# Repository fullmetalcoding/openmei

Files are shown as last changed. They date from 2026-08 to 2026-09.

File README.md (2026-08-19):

<p align="center">
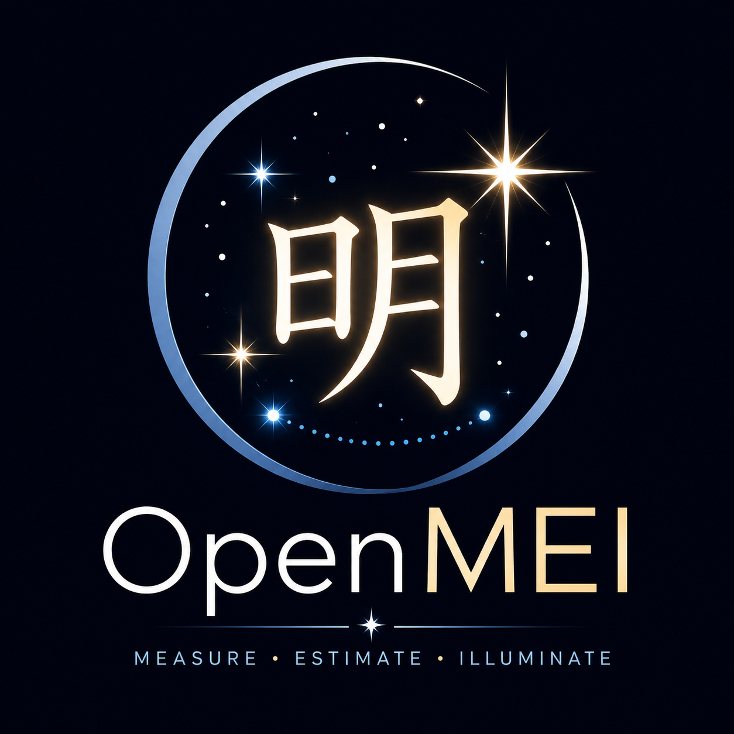
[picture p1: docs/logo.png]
OpenMEI logo
  
</p>

# OpenMEI

**OpenMEI** is an open-source **Differential Image Motion Monitor (DIMM)** application for measuring astronomical seeing.

It acquires short-exposure images of a star through a two-aperture DIMM mask, measures the differential motion of the resulting stellar images, and converts the longitudinal and transverse image-motion variances into estimates of the Fried parameter $r_0$ and atmospheric seeing.

OpenMEI is intended both as a practical seeing monitor and as an instrument whose measurement chain can be inspected, calibrated, reproduced, and validated.

Current features include:

* Real-time camera acquisition and centroid tracking
* Longitudinal and transverse differential image-motion measurement
* Fried parameter $r_0$ estimation
* Seeing FWHM estimation
* Zenith correction
* Projection of seeing onto a separate science target altitude
* Finite-exposure correction using interleaved exposures
* Centroid-noise bias estimation and subtraction
* Synthetic camera backend with known atmospheric ground truth
* ZWO ASI camera support
* SVBONY camera support
* ToupTek/ToupCam camera support
* ASCOM Alpaca `ObservingConditions` interface
* Persistent configuration and measurement metadata
* Raw centroid logging for later re-analysis (WIP)

OpenMEI is written in C++17 and uses SDL3, Dear ImGui, ImPlot, OpenGL, cpp-httplib, and nlohmann/json.

---

## What is a DIMM?

A **Differential Image Motion Monitor** measures astronomical seeing by measuring how atmospheric turbulence causes the apparent position of a star to move.

A conventional DIMM places a mask over the entrance pupil of a telescope. The mask contains two circular sub-apertures separated by a known baseline.

One aperture contains a small wedge prism or equivalent optical element that slightly deflects its beam.

Instead of one stellar image, the camera therefore sees two:

```text
                 incoming starlight
                        ↓
               ┌─────────────────┐
               │   ○         ○   │
               │             /   │
               │ aperture   /    │
               │          wedge  │
               └─────────────────┘
                       DIMM mask
                          ↓
                       telescope
                          ↓
                       camera

                     ★       ★
                    spot A   spot B
```

Both images are produced by the **same star**, but they have passed through two different regions of the telescope pupil.

Atmospheric turbulence causes the local wavefront slope over each sub-aperture to fluctuate. The two stellar images therefore move relative to one another.

The fundamental DIMM measurement is not the absolute position of either star image. It is their separation:

```math
\Delta x = x_2-x_1
\\
\Delta y = y_2-y_1
```
Because telescope tracking errors, mount vibration, and much of the mechanical motion move both images together, subtracting the two centroid positions strongly rejects common-mode motion.

This is the key advantage of the DIMM technique.

---

## Longitudinal and transverse motion

The differential displacement is resolved into two components relative to the baseline between the two sub-apertures:

* **Longitudinal** — parallel to the aperture baseline
* **Transverse** — perpendicular to the aperture baseline

For each acquired burst, OpenMEI determines the variance of both components:

```math
\sigma_l^2
```

and

```math
\sigma_t^2
```

Under Kolmogorov turbulence, these variances are related to the atmospheric coherence length, or **Fried parameter**, $r_0$.

OpenMEI represents the relationship as

```math
\sigma^2 =
K \lambda^2 D^{-1/3} r_0^{-5/3}
```

where:

* $D$ is the sub-aperture diameter
* $d$ is the center-to-center aperture separation
* $\lambda$ is the reporting wavelength
* $K$ is the longitudinal or transverse DIMM response coefficient
* $r_0$ is the Fried parameter

The geometry is commonly represented by

```math
b = \frac{d}{D}
```

For the classic Sarazin & Roddier approximation, OpenMEI uses

```math
K_l =
2c
\left[
1-\frac{0.0968}{c}b^{-1/3}
\right]
```

and

```math
K_t =
2c
\left[
1-\frac{0.1450}{c}b^{-1/3}
\right]
```

where $c=0.179$ for the original Sarazin & Roddier formulation.

OpenMEI also provides the corrected $c=0.182$ coefficient discussed in the mini-DIMM analysis by Yu et al.

The classic approximation should normally be used with

```math
\frac{d}{D} \ge 2
```

For smaller aperture separations, more exact DIMM response coefficients should be used instead.

---

## From differential motion to seeing

Once $r_0$ has been estimated, OpenMEI converts it to the conventional long-exposure seeing FWHM using

```math
\epsilon = 0.98\frac{\lambda}{r_0}
```

where $\epsilon$ is in radians.

OpenMEI normally reports seeing at the conventional reference wavelength of **500 nm**.

Because the amount of atmosphere traversed increases away from the zenith, measurements can also be normalized to zenith.

For zenith angle $z$,

```math
r_0(z) \propto (\cos z)^{3/5}
```

and therefore seeing scales as

```math
\epsilon(z) \propto (\cos z)^{-3/5}
```

OpenMEI can report both the DIMM line-of-sight seeing and the equivalent zenith seeing.

If a separate science target altitude is supplied, the zenith-normalized value can also be projected back onto the science instrument's line of sight.

---

# Building a DIMM

A basic DIMM requires surprisingly little specialized hardware:

1. A telescope
2. A two-hole aperture mask
3. A wedge prism over one aperture
4. A fast camera
5. A suitable star
6. A calibrated image scale

The measurement precision, however, depends strongly on the geometry, exposure time, optical quality, and centroid signal-to-noise ratio.

---

## 1. Telescope

The telescope should have enough clear aperture to accommodate two separated sub-apertures.

A refractor, Newtonian, Cassegrain, or similar telescope can be used. The DIMM measurement depends primarily on the entrance-pupil geometry rather than on the telescope design.

The optical system should nevertheless produce compact and reasonably symmetric stellar images. Severe aberration, defocus, or optical misalignment can bias a DIMM measurement.

A monochromatic or relatively narrow spectral band is useful, particularly with an achromatic refractor or a dispersive wedge.

A green filter centered approximately around the standard DIMM wavelength is a practical choice.

---

## 2. DIMM mask

The mask contains two equal circular apertures.

Define:

* $D$ = sub-aperture diameter
* $d$ = center-to-center separation

For use with the classic Sarazin & Roddier approximation, choose approximately

```math
d \ge 2D
```

while keeping the apertures as widely separated as the telescope entrance pupil permits.

The mask should be rigid and located at or very near the telescope entrance pupil.

The physical dimensions used for the measurement must be entered accurately in OpenMEI. Errors in $D$ and $d$ propagate directly into the inferred seeing.

### Example

For an 80 mm unobstructed telescope, a practical mask might use approximately:

```text
          telescope entrance pupil

             _________________
          .-'                 '-.
        .'                       '.
       /                           \
      |                             |
      |      ○               ○      |
      |     25 mm           25 mm   |
      |                             |
       \                           /
        '.                       .'
          '-._________________.-'

             <---- ~50 mm ---->
               center spacing
```

The exact geometry should be chosen so that neither aperture is vignetted.

[`masks/`](masks/) contains STL/step files for 3d printable masks. Currently available are: 

[`/masks/DIM_MASK_80MMx53x25.4.stl`](DIM_MASK_80MMx53x25.4.stl) A bare bones basic mask for an 80 mm class scope with sub aperture size 25.4mm and separation 53mm. Designed and tested on an Orion ST80. 

---

## 3a. Wedge prism/Wedge window

One aperture must produce a displaced image of the star.

This is normally done by mounting a shallow **optical wedge** over one of the two mask apertures.

The wedge should deflect the stellar image far enough that the two PSFs are clearly separated, but not so far that an unnecessarily large camera ROI is required.

The displacement is only an acquisition aid. OpenMEI derives seeing from changes in the **relative centroid positions**, not from the nominal wedge angle.

The direction of the wedge-induced image separation must also be known relative to the physical aperture baseline.

This is important because the longitudinal and transverse variances use different response coefficients.

OpenMEI therefore records the wedge orientation as part of the instrument configuration.

Be sure to search for "wedge window" instead of "wedge prism," as manufacturers tend to call very shallow angles windows instead.

A good prism wedge angle would be something less than 5-10 arc minutes, however you may find these to be exceeding difficult to find. 

If that is the case, consider building a Risley prism (not covered here), in which case, you should be OK to use a pair of wedge prisms roughly 30 arcmin->1 degree instead of a single wedge window.

A Risley prism has the advantage that it becomes possible to control the deflection angle of the second spot, at the cost of more complex construction.

---
## 3b. H-DIMM (Hartmann Differential Image Motion Monitor)

OpenMEI can also be used with a **Hartmann-DIMM (H-DIMM)** configuration. An H-DIMM uses the same basic two-sub-aperture geometry as a conventional DIMM, but does not require a wedge prism to separate the two stellar images.

Instead, the camera is placed slightly away from the telescope's nominal focal plane. At exact focus, light from both sub-apertures forms an image at the same detector position. When the detector is moved slightly inside or outside focus, the two sub-aperture beams are intercepted before or after they cross, producing two spatially separated stellar images.

A basic two-aperture H-DIMM mask therefore consists of:

* two equal circular sub-apertures of diameter $D$;
* a known center-to-center baseline $B$;
* no prism or other beam-steering optic.

The mask geometry should satisfy the same requirements as an ordinary DIMM. In particular, the two apertures should have the same diameter, and a baseline ratio of approximately

```math
B/D \ge 2
```

is recommended when using the standard Sarazin-Roddier DIMM response coefficients.

### Setting the Spot Separation

In an H-DIMM, the spot separation is controlled by the amount of detector defocus rather than by a prism.

For small defocus, the physical separation of the two stellar images is approximately

```math
s \approx B\frac{|\Delta z|}{f},
```

where:

* $s$ is the spot separation on the detector,
* $B$ is the sub-aperture center-to-center spacing,
* $\Delta z$ is the detector displacement from nominal focus,
* $f$ is the effective telescope focal length.

For a detector with pixel pitch $p$, the separation in pixels is approximately

```math
s_{\mathrm{px}} \approx
\frac{B|\Delta z|}{fp}.
```

For example, a mask with 25.4 mm sub-apertures separated by 53 mm on a 400 mm focal-length telescope with 2.9 µm pixels gives approximately

```math
46\ \mathrm{pixels/mm}
```

of detector defocus. With a 2× Barlow and an effective focal length of approximately 800 mm, the same geometry gives approximately

```math
23\ \mathrm{pixels/mm}.
```

A modest defocus of 1–2 mm can therefore provide a convenient tens-of-pixels separation while retaining good centroid sampling.

The maximum useful defocus is limited by the depth of focus of each individual sub-aperture. Smaller sub-apertures have a relatively large depth of focus, allowing the detector to be moved far enough from the parent telescope's focal plane to separate the two images while the individual Hartmann spots remain compact and suitable for centroiding.

### Plate-Scale Calibration

Because an H-DIMM operates away from the nominal focal plane, the effective angular scale at the detector should not be assumed from focal length and pixel size alone.

For best accuracy, **perform an empirical plate-scale calibration at the same defocus position used for measurements**. A stellar drift calibration directly measures the actual angular displacement per pixel in the operating configuration and avoids relying on an in-focus theoretical field of view.

Once calibrated, OpenMEI can process the two H-DIMM centroids in the same way as a prism-separated DIMM:

```math
\text{centroids}
\rightarrow
\text{differential motion}
\rightarrow
\sigma_L^2,\sigma_T^2
\rightarrow
r_0
\rightarrow
\text{seeing}.
```

The software does not fundamentally depend on a prism to obtain the seeing measurement; the prism or Hartmann defocus is simply the mechanism used to make the two sub-aperture images distinguishable.

### Practical Advantages

Compared with a prism-based DIMM, an H-DIMM can provide several practical advantages:

* no wedge prism or Risley pair is required;
* both sub-apertures have identical optical paths and throughput;
* there is no prism-induced chromatic dispersion;
* there is no brightness imbalance caused by prism transmission losses;
* the mask can be manufactured as a simple opaque plate with two holes;
* spot separation can be adjusted mechanically using focus rather than by changing or rotating optical elements.

The principal tradeoff is that spot separation and detector focus are coupled. The detector must be defocused enough to separate the two images while remaining within the useful depth-of-focus range of the individual sub-apertures.

For experimental use, a conventional two-hole DIMM mask can therefore be converted to an H-DIMM simply by removing the prism and operating the camera at an appropriate, calibrated defocus position.
---

## 4. Camera

DIMM measurements benefit from:

* Monochrome imaging
* Raw, uncompressed output
* Short exposure times
* High frame rates
* Small regions of interest
* Good sensitivity
* Low read noise

OpenMEI currently contains camera backends for:

* **ZWO ASI**
* **SVBONY**
* **ToupTek / ToupCam**
* **Synthetic camera**

ToupCam-compatible cameras include a number of cameras sold under other brand names.

Vendor camera libraries are loaded dynamically at runtime rather than distributed as part of OpenMEI.

See [`third_party/vendor_headers`](third_party/vendor_headers/) for information about the vendor SDK interfaces used by the project.

---

## 5. Exposure time

A DIMM attempts to measure the instantaneous image motion produced by atmospheric turbulence.

A long camera exposure averages that motion and therefore reduces the measured differential variance. The result is a systematic bias toward artificially good seeing.

OpenMEI supports paired short exposures $t$ and $2t$ and applies the modified exponential extrapolation described by Tokovinin to estimate the zero-exposure seeing.

The default base exposure is currently:

```text
5 ms
```

The appropriate exposure depends on camera sensitivity, telescope aperture, stellar brightness, seeing, and wind conditions.

Shorter exposures are preferable when sufficient signal-to-noise ratio can be maintained.

---

## 6. Frame rate

A high frame rate serves two purposes:

* It increases the number of statistically useful samples.
* It reduces temporal averaging and decorrelation problems.

Using a small camera ROI around the two stellar images is usually preferable to reading the entire sensor.

OpenMEI processes measurements in bursts and retains the number of accepted and rejected frames as part of each result.

---

## 7. Plate scale calibration

A DIMM ultimately converts centroid variance in pixels² into angular variance in radians².

The camera scale must therefore be known accurately.

OpenMEI supports several scale sources, but **measured calibration is preferred to a nominal calculation from focal length and pixel size**.

The recommended method is a stellar drift calibration.

For a star at declination $\delta$, the sidereal drift rate is approximately

```math
15.041 \cos(\delta)
```

arcseconds per second.

Measuring the number of pixels crossed over a known time therefore provides the image scale in arcseconds per pixel.

A plate-solved image can also be used.

A scale calculated from nominal telescope focal length and sensor pixel size is useful as an estimate, but manufacturing tolerances and optical accessories can make it less accurate than an actual measurement.

OpenMEI refuses to publish a seeing result until a valid plate scale has been configured.

---

# Measurement workflow

A typical observing sequence is:

```text
bright star
    ↓
two-aperture DIMM mask
    ↓
two stellar images
    ↓
short-exposure camera stream
    ↓
background estimation
    ↓
spot detection
    ↓
centroid measurement
    ↓
differential displacement
    ↓
longitudinal / transverse decomposition
    ↓
outlier rejection
    ↓
variance estimation
    ↓
centroid-noise subtraction
    ↓
DIMM response coefficients
    ↓
r₀
    ↓
seeing FWHM
    ↓
finite-exposure correction
    ↓
zenith correction
    ↓
published seeing
```

Raw centroids can be retained so that a measurement can later be reprocessed using different rejection criteria or updated analysis algorithms.

---

# Building OpenMEI

## Requirements

OpenMEI requires:

* CMake 3.21 or newer
* A C++17 compiler
* OpenGL
* Git
* Internet access during initial CMake configuration so that dependencies can be obtained through `FetchContent`

Dependencies currently fetched automatically include:

* SDL3
* GLEW
* Dear ImGui
* ImPlot
* cpp-httplib
* nlohmann/json

---

## Visual Studio 2022

OpenMEI can be configured directly from the command line:

```powershell
cmake -B build -G "Visual Studio 17 2022" -A x64
cmake --build build --config Release
```

Alternatively, open the repository directory directly in Visual Studio. Visual Studio can use the included `CMakeLists.txt` and `CMakePresets.json`.

---

## Linux

A typical Ninja build is:

```bash
cmake -S . -B build -G Ninja -DCMAKE_BUILD_TYPE=Release
cmake --build build
```

The required OpenGL development packages must be installed for the target distribution.

---

## Camera SDKs

OpenMEI does not link vendor camera libraries directly into the application.

Vendor headers are detected at CMake configuration time and determine which backends are compiled.

At runtime, the corresponding vendor DLL or shared library is loaded dynamically.

This allows the OpenMEI source tree to remain independent of vendor binary SDK distributions.

---

# Synthetic DIMM

OpenMEI always includes a synthetic camera backend.

The synthetic source generates a controlled DIMM image stream using known atmospheric parameters. This provides a ground truth against which the centroiding, variance estimation, $r_0$ inversion, exposure correction, and reporting pipeline can be tested without physical hardware.

The synthetic backend is useful for:

* Algorithm development
* Regression testing
* UI development
* Calibration experiments
* Comparing estimated seeing with known generated seeing

Additional information is available in:

[`docs/synthetic-model.md`](docs/synthetic-model.md)

---

# ASCOM Alpaca

When built with:

```text
OPENMEI_BUILD_ALPACA=ON
```

OpenMEI exposes an ASCOM Alpaca `ObservingConditions` interface.

This allows astronomy applications capable of consuming Alpaca weather or observing-condition devices to access OpenMEI seeing measurements without depending on the OpenMEI user interface.

---

# Sources of measurement error

A DIMM is conceptually simple, but accurate measurements require control of several biases.

Important error sources include:

### Finite exposure time

Temporal averaging reduces measured differential image motion and biases seeing low.

OpenMEI can compensate using paired-exposure extrapolation.

### Centroid noise

Photon noise, camera read noise, and sky background add apparent centroid motion and bias seeing high.

OpenMEI estimates this contribution and can subtract the corresponding variance before the DIMM inversion.

### Poor aperture geometry

The classic Sarazin & Roddier approximation becomes progressively less reliable as $d/D$ becomes small.

OpenMEI warns when the geometry falls below the normal validity range.

### Incorrect longitudinal/transverse orientation

Swapping the longitudinal and transverse axes applies the wrong response coefficients while still producing superficially reasonable numbers.

The mask baseline and wedge orientation should therefore be measured rather than guessed.

### Optical aberration

Defocus and other aberrations can alter the relationship between wavefront tilt and measured image centroid.

Good focus and optical alignment are important for quantitative measurements.

### Saturation

A saturated stellar image no longer provides an unbiased centroid.

OpenMEI rejects saturated frames when configured to do so.

### Low signal-to-noise ratio

Very faint stars allow camera and background noise to dominate the centroid variance.

### Tracking loss or clouds

Frames with abnormal separation or centroid excursions can be rejected, and an entire burst can be discarded if too many frames are invalid.

---

# Scientific basis and references

OpenMEI's seeing calculations are based on established DIMM and atmospheric-turbulence literature.

The most directly relevant references are listed below.

## Fried parameter and atmospheric seeing

**Fried, D. L. (1965).**
“Statistics of a Geometric Representation of Wavefront Distortion.”
*Journal of the Optical Society of America*, **55**(11), 1427–1435.
https://doi.org/10.1364/JOSA.55.001427

This paper develops the statistical description of atmospheric wavefront distortion associated with the coherence length now conventionally called the **Fried parameter**, (r_0).

OpenMEI uses the standard Kolmogorov seeing relation

```math
\epsilon \approx 0.98\frac{\lambda}{r_0}.
```

---

## Classical DIMM response

**Sarazin, M., & Roddier, F. (1990).**
“The ESO Differential Image Motion Monitor.”
*Astronomy & Astrophysics*, **227**, 294–300.

This is the principal reference for the classical DIMM method used by OpenMEI.

The longitudinal and transverse differential image-motion equations implemented by OpenMEI are derived from the Sarazin & Roddier approximation:

```math
\sigma_l^2 =
2\lambda^2r_0^{-5/3}
\left(
0.179D^{-1/3}
-------------

0.0968d^{-1/3}
\right)
```

and

```math
\sigma_t^2 =
2\lambda^2r_0^{-5/3}
\left(
0.179D^{-1/3}
-------------

0.145d^{-1/3}
\right).
```

The OpenMEI implementation rearranges these expressions into geometry-dependent response coefficients $K_l$ and $K_t$.

---

## DIMM biases, coefficients, and exposure correction

**Tokovinin, A. (2002).**
“From Differential Image Motion to Seeing.”
*Publications of the Astronomical Society of the Pacific*, **114**(800), 1156–1166.
https://doi.org/10.1086/342683

This paper revisits DIMM theory and discusses several effects important to quantitative seeing measurements, including:

* More accurate DIMM response coefficients
* The distinction between different definitions of image tilt
* CCD/read-noise bias
* Finite exposure-time bias
* Extrapolation of measurements toward zero exposure

OpenMEI's paired-exposure seeing correction is based on the modified exponential extrapolation described in this work.

For seeing estimates $\epsilon_1$ and $\epsilon_2$ obtained at exposures $t$ and $2t$,

```math
c =
\left(
\frac{\epsilon_1}{\epsilon_2}
\right)^{3/4}
```

and OpenMEI evaluates

```math
\epsilon_0 =
\frac{1}{2}
\left(
c\epsilon_1 +
c^{7/3}\epsilon_2
\right)
```

as an estimate of the zero-exposure seeing.

---

## Mini-DIMM coefficient correction

**Yu, L., Tan, F., Jing, X., & Shen, H. (2020).**
“Mini-DIMM: theory analysis and experimental validation.”
*Optical Engineering*, **59**(12), 120501.
https://doi.org/10.1117/1.OE.59.12.120501

Yu et al. compare the commonly used Sarazin & Roddier approximation with the more exact treatment and note that the leading coefficient conventionally written as `0.179` is more accurately `0.182`.

The work also emphasizes that the classical approximation is reliable for approximately

```math
d/D \ge 2
```

while more accurate coefficients become increasingly important for smaller baseline-to-aperture ratios.

OpenMEI therefore supports both:

```text
Sarazin & Roddier       c = 0.179
Sarazin & Roddier Mini  c = 0.182
```

and also permits manually supplied longitudinal and transverse response coefficients.

---

# Reproducibility

OpenMEI treats instrument configuration as part of the measurement.

Parameters affecting a reported result should be retained with the observation wherever practical, including:

* Sub-aperture diameter
* Aperture baseline
* Wedge orientation
* Plate scale
* Plate-scale calibration method
* Exposure time
* Camera cadence
* Reporting wavelength
* Centroid configuration
* Rejection configuration
* Number of accepted/rejected frames
* Zenith correction
* Site and target geometry

The goal is that a published seeing measurement can be traced back to the configuration and intermediate data from which it was derived.

For scientific datasets, retaining the raw centroid time series is strongly recommended.

---

# Third-party software and camera SDKs

OpenMEI source code is distributed under the license in [`LICENSE.txt`](LICENSE.txt).

Third-party dependencies retain their respective licenses.

Vendor camera SDK headers under:

[`third_party/vendor_headers`](third_party/vendor_headers/)

are vendor-supplied interface definitions and are **not covered by the OpenMEI license**.

OpenMEI does not distribute vendor SDK DLLs, shared libraries, or static libraries as part of its source code.

---

# Contributing

Bug reports, validation results, hardware compatibility reports, and pull requests are welcome.

Particularly useful contributions include:

* Tests against calibrated professional DIMM instruments
* Additional camera backends
* Improved centroid algorithms
* Better finite-exposure corrections
* Validation of response coefficients
* Additional synthetic-turbulence tests
* Cross-platform testing
* Documentation for reproducible DIMM mask designs

When changing the seeing-estimation algorithm, please include the scientific reference or derivation supporting the change and, where possible, a test against the synthetic backend or another known reference.

---

# License

OpenMEI is licensed under the terms in [`LICENSE.txt`](LICENSE.txt).

Third-party material is excluded from the OpenMEI license and remains subject to its respective upstream terms.

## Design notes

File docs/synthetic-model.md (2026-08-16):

# The synthetic source: model, algorithm, and limits

`src/camera/backends/synthetic_backend.cpp` generates a DIMM spot pair from a
known Fried parameter so the measurement chain can be checked against ground
truth. This note records what is physically derived, what is a modelling
choice, and what the model cannot be used to validate.

**Provenance warning.** This is not an implementation of any single paper. It
was assembled from standard relations plus several phenomenological choices.
Where a coefficient comes from a specific source it is marked; where it is a
convenience it is marked as such. Anyone relying on this for published work
should check the primary literature rather than this file.

---

## 1. Seeing to Fried parameter

    epsilon = 0.98 * lambda / r0

The Kolmogorov long-exposure FWHM relation. Inverted to get `r0` from the
seeing the user sets. Standard; traceable to Fried and to Roddier's 1981
review of atmospheric turbulence in optical astronomy.

## 2. Differential motion variance — Sarazin & Roddier

    sigma_l^2 = 2 lambda^2 r0^(-5/3) [0.179 D^(-1/3) - 0.0968 d^(-1/3)]
    sigma_t^2 = 2 lambda^2 r0^(-5/3) [0.179 D^(-1/3) - 0.1450 d^(-1/3)]

with sigma in radians, D the sub-aperture diameter and d the baseline, both in
metres. Longitudinal is parallel to the line joining the sub-apertures;
transverse is perpendicular. Valid for D/d <= 0.5.

Source: Sarazin & Roddier (1990), the ESO DIMM paper. The coefficients were
checked against secondary sources during development; the primary paper was not
consulted directly.

Two known refinements, neither implemented in the generator:

- The mini-DIMM analysis argues the leading 0.179 should be 0.182, on the
  grounds that Sarazin & Roddier's expressions approximate Sasiela's result and
  hold for d >= 2D.
- Tokovinin (2002) gives more accurate response coefficients as a function of
  b = d/D, and notes that a DIMM measures Zernike tilt rather than image
  centroid — so G-tilt and Z-tilt coefficient sets differ. Reference point: at
  b = 2.5 the G-tilt values are K_l = 0.1956, K_t = 0.1270. The published K(b)
  fit is not reproduced in this codebase; `CoefficientModel::Manual` exists so
  the values can be entered from the paper.

**Circularity.** The generator uses these relations to produce motion and the
analysis inverts the same relations. The coefficients cancel exactly. This
validates centroiding, statistics, axis handling and the inversion arithmetic —
it cannot validate whether the coefficients themselves are correct. Only a
second instrument or the literature can settle that.

## 3. Temporal correlation — the largest liberty taken

Differential motion evolves as an Ornstein-Uhlenbeck process:

    x(t+dt) = a x(t) + sigma sqrt(1 - a^2) N(0,1),   a = exp(-dt/tau)

stationary with variance sigma^2 and correlation time tau, exposed as
`coherenceTimeMs`.

**This is a modelling convenience, not atmospheric physics.** An OU process has
a Lorentzian power spectrum: flat below the corner frequency, falling as f^-2
above it. The real temporal spectrum of atmospheric tilt under frozen flow goes
roughly as f^(-2/3) at low frequency and f^(-11/3) at high frequency.

So relative to reality this model has too little low-frequency power and too
much high-frequency power. Since a finite exposure preferentially averages away
high frequencies, the consequence is directional: **the simulator probably
overstates exposure-time bias.**

The coherence time is also a free parameter here rather than derived. Physically
tau_0 ≈ 0.31 r0 / v_eff, so it is set by the same turbulence that sets r0
together with the wind profile — changing seeing without changing tau is not
something the atmosphere does.

## 4. Exposure-time integration

Each frame is built from N substeps spanning the exposure, with the atmosphere
advanced between them and the instantaneous PSF accumulated. The recorded image
is therefore the integral of a moving PSF: displaced by the flux-weighted mean
position and broadened by the spread, which is what a real exposure does.

Variance retention over a window T, exact for an OU process:

    R(T) = (2 tau / T) [1 - (tau/T)(1 - exp(-T/tau))]

Used only for the panel's prediction, not in the generator. Since the underlying
process is not really OU, this curve is indicative rather than authoritative.

The correction under test is Tokovinin's modified exponential extrapolation from
an interleaved pair:

    c1 = (eps1/eps2)^(3/4)
    eps0 = 0.5 (c1 eps1 + c1^(7/3) eps2)

Published bias magnitudes for calibration: Chilean site measurements alternating
10 and 20 ms give median seeing around 0.66-0.76" extrapolated to zero exposure
against 0.48-0.56" raw at 20 ms — roughly 25-30% low. Dome Fuji estimate their
1 ms exposures are biased under 3%.

## 5. Image formation

Each spot is an elliptical Gaussian:

    I(r) = (F / 2 pi s_maj s_min) exp(-[a^2/2s_maj^2 + b^2/2s_min^2])

with a and b the coordinates along and across the deviation axis. A real PSF is
an Airy pattern plus a seeing halo, better described by a Moffat profile; the
Gaussian is an approximation that understates the wings, which is where a
thresholded centroider gets much of its leverage.

**Wedge transmission.** Only the deviated spot passes through glass, so its flux
is scaled by `wedgeTransmission` — 0.92 for uncoated (two ~4% Fresnel surfaces),
~0.99 AR-coated.

**Chromatic streak.** A thin wedge deviates by delta = (n-1) alpha, and the
fractional spread across the passband is 1/V for Abbe number V. So the streak
length is delta/V, scaled by the fraction of the visible band transmitted. It is
folded into the major axis as the Gaussian equivalent of a uniform smear:

    s_maj = sqrt(sigma^2 + streak^2 / 12)

Limitation: this is **symmetric**. A real dispersion fan is weighted by the
source spectrum and the detector response, so it is asymmetric and would shift
the centroid, not merely broaden it. The model reproduces the precision loss
along the measurement axis but not that bias.

## 6. Scintillation

Per-aperture flux modulation, again OU, with a settable index and an
inter-aperture correlation coefficient. Entirely phenomenological. Real
scintillation follows from Fresnel propagation and depends on aperture size
relative to the Fresnel scale, zenith angle, and the Cn^2 profile; the
correlation between two sub-apertures depends on their separation relative to
that scale. None of that is modelled — the numbers are set by hand.

## 7. Detector

Standard CCD equation. Signal plus sky is clipped at full well, Poisson noise
applied, Gaussian read noise added, then converted to ADU:

    e_per_ADU = fullWell / (2^bits - 1) / 10^(gain/200)

The gain exponent follows the ZWO convention of 0.1 dB units. Two independent
ceilings are enforced — the well fills, and the ADC clips — because either one
flattens the core and biases the centroid toward better seeing.

Not modelled: dark current, fixed-pattern noise, amp glow, non-linearity near
saturation, rolling-shutter row timing.

## 8. Algorithm, per frame

    1. sigma_l, sigma_t from seeing via Sarazin & Roddier
    2. N = ceil(exposure / (tau/10)), clamped to [1, 64]
    3. for each substep:
         advance diff_l, diff_t, tracking, scintillation by dt (OU)
         place spot A at mid - sep/2 + diff/2
         place spot B at mid + sep/2 - diff/2
         accumulate both Gaussians at amplitude/N
         accumulate flux-weighted true positions
    4. publish ground truth (exposure-averaged, flux-weighted centroids)
    5. per pixel: clip to full well, Poisson, read noise, convert, quantise

Step 4 is what makes the centroider testable: the residual against those
positions is the centroider's error and nothing else.

## 9. What this can and cannot validate

Can:

- centroid accuracy, including pixel-phase bias (static + noise-free mode)
- centroid precision against the photon-noise floor
- variance accumulation, axis projection, rejection gates
- common-mode cancellation (vary tracking wander; r0 must not move)
- isotropy (rotate the baseline angle; r0 must not move)
- noise-bias subtraction (vary flux; r0 must not move)
- that the t/2t machinery recovers *the bias this model injects*

Cannot:

- the response coefficients — the generator and the analysis share them
- whether the exposure correction is right for the real atmosphere, since the
  temporal spectrum here is wrong in a known direction
- anything about real optics: aberrations, non-Gaussian PSF wings, focus drift
- absolute seeing accuracy at any level

The last point is the important one. Agreement with the synthetic source is
necessary but nowhere near sufficient. Absolute validation requires a second
instrument.

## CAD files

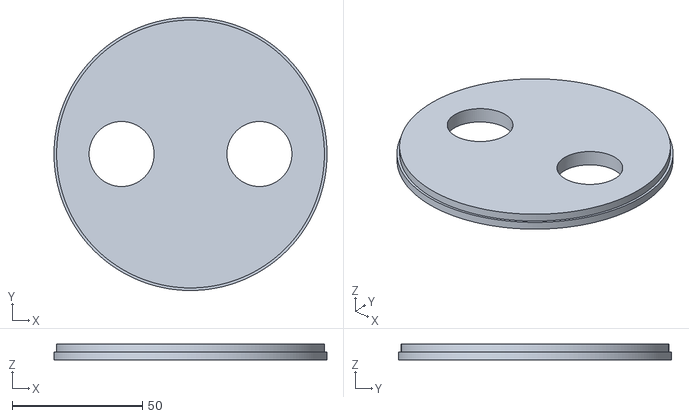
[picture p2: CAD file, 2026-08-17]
masks/DIMM_MASK_80MMx53x25.4.stl
105.0 x 105.0 x 6.00

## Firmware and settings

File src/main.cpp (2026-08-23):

// main.cpp -- OpenMei application shell.
//
// SDL3 window + OpenGL 3.3 core + GLEW + Dear ImGui, a menu bar, and a
// PHD2-style status bar with condition lamps. No measurement code yet; this
// is the frame everything else hangs off.

#include <SDL3/SDL.h>
#include <GL/glew.h>          // must be included before any GL headers

#include "imgui.h"
#include "implot.h"
#include "imgui_internal.h"   // BeginViewportSideBar -- see note at StatusBar()
#include "backends/imgui_impl_sdl3.h"
#include "backends/imgui_impl_opengl3.h"

#include "camera/registry.h"
#include "camera/stream.h"
#include "camera/backends/synthetic_backend.h"
#include "dimm/config.h"
#include "dimm/processor.h"
#include "dimm/seeing.h"
#include "ui/camera_dialog.h"
#include "app/seeing_history.h"
#include "app/settings_store.h"
#include "app/uuid.h"
#ifdef OPENMEI_ALPACA
#include "net/alpaca_server.h"
#endif
#include "ui/dimm_panel.h"
#include "ui/history_panel.h"
#include "ui/settings_dialog.h"
#include "ui/viewport.h"

#include <algorithm>
#include <chrono>
#include <cstdio>
#include <deque>
#include <string>

// =============================================================================
//  Application state
// =============================================================================

namespace mei {

    enum class Severity { Info, Warning, Error };

    struct LogEntry {
        Severity    severity;
        std::string text;
        Uint64      when;      // SDL_GetTicks()
    };

    struct MeiApp {
        bool running = true;

        // Condition lamps. Both start false -- an uncalibrated DIMM must not be
        // able to publish a number, and the UI should say so from the first frame.
        bool calibrated = false;   // plate scale + geometry validated
        bool haveDarks = false;   // dark / hot-pixel library loaded

        // Most recent status line, plus a short history for a future log window.
        LogEntry             status{ Severity::Info, "Ready. No calibration loaded.", 0 };
        std::deque<LogEntry> history;

        bool showDemo = false;

        // Equipment. The registry owns every backend and the live connection.
        CameraRegistry     cameras;
        ui::CameraDialog   cameraDialog;
        StreamController   stream;
        ui::Viewport       viewport;

        // Requested stream settings. Applied through ICamera::configure(), which
        // clamps to hardware granularity and hands back what was actually set.
        StreamConfig want{};
        bool showSynthPanel = false;

        // Measurement configuration and its editor.
        AppSettings        prefs;
        DimmConfig& dimm = prefs.dimm;   // alias: everything already uses this
        ui::SettingsDialog settings;
        bool               prefsDirty = false;
        uint64_t           lastPrefsSaveMs = 0;
        DimmProcessor      processor;
        bool               showDimmPanel = true;

        // Named distinctly from the LogEntry deque above -- both are "history" in
        // plain English, and the collision is not obvious at the declaration.
        SeeingHistory      seeingHistory;
        bool               showHistoryPanel = false;

#ifdef OPENMEI_ALPACA
        AlpacaServer  alpaca;
        AlpacaConfig& alpacaCfg = prefs.alpaca;
        bool         showAlpacaPanel = false;
        // Only republish when a genuinely new burst completes, so clients see a
        // stable value between measurements rather than a field that churns.
        uint64_t     lastPublishedBurst = 0;
#endif

        // Spot overlay, PHD2-style.
        bool overlayShow = true;
        bool overlayWindows = true;   // centroid window boxes
        bool overlayAxis = false;  // longitudinal / transverse axes
        bool overlayLabels = true;

        bool isSynthetic() const {
            return cameras.connectedDesc().backendId == "synthetic";
        }

        bool cameraConnected() const { return cameras.connected(); }
        bool cameraStreaming() const { return stream.running(); }

        void setStatus(Severity sev, std::string text) {
            status = { sev, std::move(text), SDL_GetTicks() };
            history.push_back(status);
            if (history.size() > 512) history.pop_front();
        }
    };

} // namespace mei

// =============================================================================
//  UI helpers
// =============================================================================

namespace mei::ui {


    // PHD2-style condition lamp: a small filled box with a short label, green when
    // the condition is satisfied and amber when it isn't. Hover for detail.
    static void Lamp(const char* label, bool ok, const char* tipOk, const char* tipBad) {
        const ImGuiStyle& style = ImGui::GetStyle();
        const ImVec2 textSize = ImGui::CalcTextSize(label);
        const ImVec2 pad = ImVec2(style.FramePadding.x, style.FramePadding.y * 0.5f);
        const ImVec2 box = ImVec2(textSize.x + pad.x * 2.0f, textSize.y + pad.y * 2.0f);

        const ImU32 bg = ok ? IM_COL32(40, 140, 60, 255)    // green
            : IM_COL32(170, 120, 20, 255);   // amber
        const ImU32 fg = IM_COL32(235, 235, 235, 255);

        const ImVec2 p = ImGui::GetCursorScreenPos();
        ImDrawList* dl = ImGui::GetWindowDrawList();
        dl->AddRectFilled(p, ImVec2(p.x + box.x, p.y + box.y), bg, 3.0f);
        dl->AddText(ImVec2(p.x + pad.x, p.y + pad.y), fg, label);

        // Dummy reserves the layout rect so IsItemHovered() and SameLine() work.
        ImGui::Dummy(box);
        if (ImGui::IsItemHovered(ImGuiHoveredFlags_AllowWhenDisabled)) {
            ImGui::SetTooltip("%s", ok ? tipOk : tipBad);
        }
    }

    static ImU32 SeverityColor(Severity s) {
        switch (s) {
        case Severity::Error:   return IM_COL32(235, 90, 80, 255);
        case Severity::Warning: return IM_COL32(230, 180, 60, 255);
        default:                return IM_COL32(210, 210, 210, 255);
        }
    }

    // Configure a sensible default ROI and start the grab thread. A DIMM wants a
    // small window at high cadence, not a full frame.
    static void startStream(MeiApp& app) {
        ICamera* cam = app.cameras.camera();
        if (!cam) return;

        const Caps& c = cam->caps();
        StreamConfig w = app.want;
        if (w.width <= 0) {
            // Prefer 16-bit. Quantisation is not what limits centroid precision --
            // photon noise is, by an order of magnitude -- but 8 bits leaves no
            // saturation headroom, and a clipped core biases the measurement toward
            // BETTER seeing by flattening the peak and suppressing apparent motion.
            // The bandwidth cost is only paid during full-frame acquisition; the
            // measurement ROI is small enough that 16-bit is free there.
            if (c.isColor) {
                // A CFA modulates pixel sensitivity in a 2x2 pattern, which biases
                // the centroid by an amount that varies with sub-pixel position.
                // Hardware mono binning sums each 2x2 block so the modulation
                // cancels exactly. Half the resolution, but an unbiased centroid --
                // and interpolating instead would only correlate neighbours.
                w.bin = (c.hasMonoBin && std::find(c.bins.begin(), c.bins.end(), 2)
                    != c.bins.end()) ? 2 : 1;
                w.monoBin = (w.bin >= 2);
                w.format = PixelFormat::Bayer8;
                for (auto f : c.formats) if (f == PixelFormat::Bayer16) w.format = f;
            }
            else {
                w.bin = 1;
                w.format = PixelFormat::Mono8;
                for (auto f : c.formats) if (f == PixelFormat::Mono16) w.format = f;
            }
            // ZWO's high-speed mode buys throughput by reading out through a
            // lower-bit ADC, so a RAW16 frame would carry ~10 real bits in a 16-bit
            // container -- and nothing in the API reports that. Never combine them.
            w.highSpeed = (bytesPerPixel(w.format) == 1);
            // ROI is in binned coordinates.
            w.width = std::min(800, c.maxWidth / w.bin);
            w.height = std::min(600, c.maxHeight / w.bin);
            w.x = (c.maxWidth / w.bin - w.width) / 2;
            w.y = (c.maxHeight / w.bin - w.height) / 2;

            w.exposureUs = 5000;
            w.gain = c.gain.supported ? c.gain.def : 200.0;
            // 100 = let the camera use its full rated USB throughput. Lower this
            // if you see torn frames or timeouts on a weak host controller; it is
            // the first knob to turn when chasing drops, not the last.
            w.usbBandwidth = 100;
        }

        std::string err;
        app.want = cam->configure(w, err);
        if (!err.empty()) { app.setStatus(Severity::Error, "Configure failed: " + err); return; }

        // Analysis sees every frame; the display tap deliberately does not.
        app.processor.setConfig(app.dimm);
        // The processor drives the t/2t alternation but never touches the camera.
        app.processor.setExposureSetter([&app](int64_t us) {
            ICamera* c = app.cameras.camera();
            if (!c) return false;
            std::string e;
            const bool ok = c->setExposureUs(us, e);
            if (ok) app.want.exposureUs = c->config().exposureUs;
            return ok;
            });
        const bool synth = app.isSynthetic();
        app.stream.setAnalysisSink([&app, synth](const Frame& f) {
            app.processor.onFrame(f, synth);
            });

        if (!app.stream.start(cam, err)) {
            app.setStatus(Severity::Error, "Start failed: " + err);
            return;
        }
        char buf[160];
        std::snprintf(buf, sizeof(buf),
            "Streaming %dx%d @ (%d,%d) bin%d, %s%s, %.1f ms, gain %.0f",
            app.want.width, app.want.height, app.want.x, app.want.y,
            app.want.bin, toString(app.want.format),
            app.want.monoBin ? " (mono bin)" : "",
            app.want.exposureUs / 1000.0, app.want.gain);
        app.setStatus(Severity::Info, buf);
        app.prefsDirty = true;
    }

    static void SyntheticPanel(MeiApp& app) {
        if (!app.showSynthPanel) return;
        ImGui::SetNextWindowSize(ImVec2(360, 0), ImGuiCond_FirstUseEver);
        if (!ImGui::Begin("Synthetic source", &app.showSynthPanel)) { ImGui::End(); return; }

        SyntheticParams& p = syntheticParams();
        ImGui::TextWrapped("Ground truth for validating the measurement chain. "
            "Whatever seeing is set here is what the analysis must "
            "recover.");
        ImGui::Separator();

        float seeing = float(p.seeingArcsec);
        if (ImGui::SliderFloat("Seeing (arcsec)", &seeing, 0.4f, 6.0f, "%.2f"))
            p.seeingArcsec = seeing;

        float sep = float(p.separationPx);
        if (ImGui::SliderFloat("Spot separation (px)", &sep, 20.0f, 400.0f, "%.0f"))
            p.separationPx = sep;

        float fwhm = float(p.spotFwhmPx);
        if (ImGui::SliderFloat("Spot FWHM (px)", &fwhm, 1.5f, 20.0f, "%.2f"))
            p.spotFwhmPx = fwhm;

        float scale = float(p.plateScale);
        if (ImGui::SliderFloat("Plate scale (\"/px)", &scale, 0.10f, 3.0f, "%.3f"))
            p.plateScale = scale;

        float angle = float(p.axisAngleDeg);
        if (ImGui::SliderFloat("Baseline angle (deg)", &angle, 0.0f, 180.0f, "%.1f"))
            p.axisAngleDeg = angle;

        ImGui::Checkbox("Wedge along baseline", &p.wedgeAlongBaseline);
        ImGui::SetItemTooltip("Off simulates a wedge clocked across the baseline, "
            "which swaps the longitudinal and transverse axes.");

        float flux = float(p.starFluxE);
        if (ImGui::SliderFloat("Star flux (e- @ 10ms)", &flux, 1000.0f, 500000.0f,
            "%.0f", ImGuiSliderFlags_Logarithmic))
            p.starFluxE = flux;

        float tau = float(p.coherenceTimeMs);
        if (ImGui::SliderFloat("Coherence time (ms)", &tau, 0.5f, 30.0f, "%.1f"))
            p.coherenceTimeMs = tau;
        ImGui::SetItemTooltip("How fast the wavefront tilt decorrelates. Together "
            "with exposure this sets the exposure-time bias.");

        float common = float(p.trackingRmsPx);
        if (ImGui::SliderFloat("Tracking wander (px)", &common, 0.0f, 20.0f, "%.1f"))
            p.trackingRmsPx = common;
        ImGui::SetItemTooltip("Common-mode motion. A correct analysis is insensitive "
            "to this -- it cancels in the difference.");

        ImGui::SeparatorText("Wedge");
        float trans = float(p.wedgeTransmission);
        if (ImGui::SliderFloat("Transmission", &trans, 0.70f, 1.00f, "%.3f"))
            p.wedgeTransmission = trans;
        ImGui::SetItemTooltip("Only the deviated spot passes through glass. 0.92 is "
            "uncoated (two ~4%% Fresnel surfaces), ~0.99 AR-coated.");

        float band = float(p.bandwidthNm);
        if (ImGui::SliderFloat("Passband (nm)", &band, 10.0f, 300.0f, "%.0f"))
            p.bandwidthNm = band;
        ImGui::SetItemTooltip("Sets the chromatic streak on the deviated spot. "
            "Narrowing the band is what makes the wedge usable.");

        // The streak is deviation/Abbe, so it scales with separation -- which is
        // why a fixed 30' wedge at a long focal length is unusable while the same
        // glass in a Risley pair set to a small net deviation is fine.
        {
            const double bandFrac = std::clamp(p.bandwidthNm / 300.0, 0.0, 1.0);
            const double streak = (p.separationPx / std::max(1.0, p.abbeNumber)) * bandFrac;
            const double sig = p.spotFwhmPx / 2.35482;
            const double sMaj = std::sqrt(sig * sig + streak * streak / 12.0);
            const double ellip = 1.0 - sig / sMaj;
            ImGui::TextDisabled("Streak %.2f px -> FWHM %.2f x %.2f px, ellipticity %.3f",
                streak, sMaj * 2.35482, p.spotFwhmPx, ellip);
            if (ellip > 0.15) {
                ImGui::TextColored(ImVec4(0.90f, 0.70f, 0.25f, 1.0f),
                    "Spot B is badly smeared -- narrow the passband "
                    "or reduce the deviation.");
            }
        }

        ImGui::SeparatorText("Detector");
        float fw = float(p.fullWellE);
        if (ImGui::SliderFloat("Full well (e-)", &fw, 5000.0f, 100000.0f, "%.0f"))
            p.fullWellE = fw;
        float rn = float(p.readNoiseE);
        if (ImGui::SliderFloat("Read noise (e-)", &rn, 0.5f, 10.0f, "%.2f"))
            p.readNoiseE = rn;

        ImGui::SeparatorText("Scintillation");
        float sc = float(p.scintillationIndex);
        if (ImGui::SliderFloat("Index", &sc, 0.0f, 0.30f, "%.3f"))
            p.scintillationIndex = sc;
        float scc = float(p.scintillationCorr);
        if (ImGui::SliderFloat("Aperture correlation", &scc, 0.0f, 1.0f, "%.2f"))
            p.scintillationCorr = scc;

        ImGui::Separator();
        ImGui::Checkbox("Inject hot pixels", &p.injectHotPixels);
        ImGui::Checkbox("Inject field star", &p.injectFieldStar);
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
int main(int, char**) {
    if (!SDL_Init(SDL_INIT_VIDEO)) { fatal("SDL_Init failed"); return 1; }

    // Request 3.3 core -- enough for ImGui's GL3 backend, and what GLEW will
    // resolve against. Attributes must be set before context creation.
    SDL_GL_SetAttribute(SDL_GL_CONTEXT_MAJOR_VERSION, 3);
    SDL_GL_SetAttribute(SDL_GL_CONTEXT_MINOR_VERSION, 3);
    SDL_GL_SetAttribute(SDL_GL_CONTEXT_PROFILE_MASK, SDL_GL_CONTEXT_PROFILE_CORE);
    SDL_GL_SetAttribute(SDL_GL_DOUBLEBUFFER, 1);
    SDL_GL_SetAttribute(SDL_GL_DEPTH_SIZE, 24);
#ifdef __APPLE__
    SDL_GL_SetAttribute(SDL_GL_CONTEXT_FLAGS, SDL_GL_CONTEXT_FORWARD_COMPATIBLE_FLAG);
#endif

    const SDL_WindowFlags winFlags =
        SDL_WINDOW_OPENGL | SDL_WINDOW_RESIZABLE | SDL_WINDOW_HIGH_PIXEL_DENSITY;

    SDL_Window* window = SDL_CreateWindow("OpenMEI", 1280, 800, winFlags);
    if (!window) { fatal("SDL_CreateWindow failed"); SDL_Quit(); return 1; }
    SDL_SetWindowMinimumSize(window, 800, 500);

    SDL_GLContext gl = SDL_GL_CreateContext(window);
    if (!gl) { fatal("SDL_GL_CreateContext failed"); SDL_DestroyWindow(window); SDL_Quit(); return 1; }
    SDL_GL_MakeCurrent(window, gl);
    SDL_GL_SetSwapInterval(1);   // vsync; this is a monitoring UI, not a game

    // GLEW must be initialised after a context is current. glewExperimental is
    // required for core profiles or glewInit reports functions as unavailable.
    glewExperimental = GL_TRUE;
    if (GLenum err = glewInit(); err != GLEW_OK) {
        SDL_LogError(SDL_LOG_CATEGORY_APPLICATION, "glewInit failed: %s",
            reinterpret_cast<const char*>(glewGetErrorString(err)));
        SDL_GL_DestroyContext(gl);
        SDL_DestroyWindow(window);
        SDL_Quit();
        return 1;
    }
    // glewInit() can leave a spurious GL_INVALID_ENUM on core profiles. Clear it
    // so it does not surface later and look like our own bug.
    glGetError();

    SDL_Log("GL %s | GLSL %s | %s",
        reinterpret_cast<const char*>(glGetString(GL_VERSION)),
        reinterpret_cast<const char*>(glGetString(GL_SHADING_LANGUAGE_VERSION)),
        reinterpret_cast<const char*>(glGetString(GL_RENDERER)));

    // --- Dear ImGui ----------------------------------------------------------
    IMGUI_CHECKVERSION();
    ImGui::CreateContext();
    // ImPlot keeps its own context alongside ImGui's; without this the first
    // plot call dereferences null.
    ImPlot::CreateContext();
    ImGuiIO& io = ImGui::GetIO();
    io.ConfigFlags |= ImGuiConfigFlags_NavEnableKeyboard;
    io.ConfigFlags |= ImGuiConfigFlags_DockingEnable;
    io.IniFilename = "openmei_layout.ini";

    ImGui::StyleColorsDark();
    ImGui_ImplSDL3_InitForOpenGL(window, gl);
    ImGui_ImplOpenGL3_Init("#version 330");

    mei::MeiApp app;
    {
        std::string perr;
        if (!mei::loadSettings(app.prefs, perr)) {
            app.setStatus(mei::Severity::Warning,
                "Settings could not be loaded, using defaults: " + perr);
        }
        // Identity is a property of the installation, not of the Alpaca server
        // -- which is why it is generated here and unconditionally, rather than
        // by a component that may be compiled out.
        if (app.prefs.installationId.empty()) {
            app.prefs.installationId = mei::generateUuid();
            app.prefsDirty = true;
        }
#ifdef OPENMEI_ALPACA
        app.prefs.alpaca.uniqueId = app.prefs.installationId;
#endif
        if (app.prefs.haveStream) app.want = app.prefs.stream;
        SDL_Log("settings: %s", mei::settingsPath().c_str());
    }

    // --- Main loop -----------------------------------------------------------
    while (app.running) {
        SDL_Event ev;
        while (SDL_PollEvent(&ev)) {
            ImGui_ImplSDL3_ProcessEvent(&ev);
            if (ev.type == SDL_EVENT_QUIT) app.running = false;
            if (ev.type == SDL_EVENT_WINDOW_CLOSE_REQUESTED &&
                ev.window.windowID == SDL_GetWindowID(window)) {
                app.running = false;
            }
        }

        // Minimised: skip rendering but keep the event pump alive.
        if (SDL_GetWindowFlags(window) & SDL_WINDOW_MINIMIZED) {
            SDL_Delay(10);
            continue;
        }

        ImGui_ImplOpenGL3_NewFrame();
        ImGui_ImplSDL3_NewFrame();
        ImGui::NewFrame();

        // Order matters: the menu bar and status bar each shrink the viewport
        // work area, so the central region must be built after both.
        mei::ui::MenuBar(app);
        mei::ui::StatusBar(app);
        mei::ui::CentralArea(app);
        mei::ui::SyntheticPanel(app);

        {
            // One point per completed burst. Keyed on the burst counter for the
            // same reason the Alpaca feed is: a steady atmosphere produces
            // near-identical values, so nothing derived from the numbers
            // themselves can distinguish a new result from a repeat.
            const mei::DimmStatus hs = app.processor.status();
            if (hs.haveResult) {
                using namespace std::chrono;
                const double nowS = double(duration_cast<seconds>(
                    system_clock::now().time_since_epoch()).count());
                app.seeingHistory.add(hs.result, nowS);
            }
        }
        mei::ui::SeeingHistoryPanel(&app.showHistoryPanel, app.seeingHistory,
            app.dimm, app.prefs.historyView,
            app.processor.status().state != mei::DimmState::Idle);

#ifdef OPENMEI_ALPACA
        mei::ui::AlpacaPanel(app);
        {
            // Republish on each completed burst. Keyed on the burst counter,
            // not on the measured values: a steady atmosphere produces
            // near-identical results burst after burst, and frame counts are
            // the same every time by construction, so anything derived from the
            // numbers themselves silently stops updating.
            const mei::DimmStatus ds = app.processor.status();
            if (ds.haveResult && ds.result.burstSequence != app.lastPublishedBurst) {
                app.lastPublishedBurst = ds.result.burstSequence;
                app.alpaca.publish(ds.result, app.dimm);
            }
        }
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

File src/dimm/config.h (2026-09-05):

// config.h -- everything that defines a DIMM measurement.
//
// Split by concern rather than by UI layout. Anything here that affects a
// published number must also end up in the per-burst record: a seeing value
// nobody can reconstruct the conditions for is worth very little.

#pragma once

#include <cstdint>
#include <string>

namespace mei {

    // -----------------------------------------------------------------------------
    //  Optics
    // -----------------------------------------------------------------------------

    // The wedge deviates one subaperture's image. Which way it is clocked relative
    // to the mask baseline is a hardware fact the software cannot infer from an
    // image -- and getting it wrong silently swaps sigma_l and sigma_t, which are
    // inverted with different coefficients. Wrong answer, no symptom.
    enum class WedgeOrientation {
        AlongBaseline,        // separation vector IS the longitudinal axis
        AcrossBaseline,       // separation vector is the TRANSVERSE axis
        ExplicitAngle         // measured angle from the separation vector
    };

    struct OpticsConfig {
        double subApertureMm = 25.0;    // D -- mask hole diameter
        double baselineMm = 120.0;   // d -- hole centre separation

        WedgeOrientation wedgeOrientation = WedgeOrientation::AlongBaseline;
        double wedgeAngleFromSeparationDeg = 0.0;   // used when ExplicitAngle

        // Only used to predict where the second spot should land, as an acquisition
        // sanity check. Never used to calibrate: shallow wedges carry proportionally
        // large manufacturing tolerance.
        bool   haveWedgeSpec = false;
        double wedgeApexArcmin = 30.0;
        double wedgeIndex = 1.5168;   // N-BK7 at 546 nm
        double wedgeAbbe = 64.2;
        double separationTolerancePct = 10.0;

        // Which subaperture carries the wedge. That image is dimmer (Fresnel loss)
        // and chromatically streaked along the deviation axis -- an asymmetry that
        // lies on a measurement axis by construction.
        bool   wedgeOnSpotB = true;

        double b() const {              // baseline-to-aperture ratio
            return subApertureMm > 0.0 ? baselineMm / subApertureMm : 0.0;
        }
        // Below ~2 the Sarazin & Roddier approximation degrades and the two terms
        // being differenced are close in size, amplifying geometry errors.
        bool geometryValid() const { return b() >= 2.0; }
    };

    // -----------------------------------------------------------------------------
    //  Plate scale
    // -----------------------------------------------------------------------------

    enum class ScaleMethod {
        NotCalibrated,
        Drift,          // star trail timing -- the recommended method
        PlateSolve,     // imported from an external solve, mask removed
        Computed,       // focal length x pixel size; an estimate, not a measurement
        Manual          // entered by hand -- legitimate against a synthetic source,
                        // where the scale is a known generator parameter
    };

    struct CalibrationConfig {
        double      arcsecPerPixel = 0.0;
        ScaleMethod method = ScaleMethod::NotCalibrated;

        // Provenance travels with every published measurement. When someone
        // questions the numbers six months from now, this is what settles it.
        std::string calibratedUtc;          // ISO-8601
        double      fitResidualPx = 0.0;   // drift fit RMS
        double      declinationDeg = 0.0;   // drift rate is 15.041*cos(dec) "/s
        double      driftSeconds = 0.0;
        std::string notes;

        // Convenience path only; flagged as an estimate wherever it is reported.
        double focalLengthMm = 750.0;
        double pixelSizeUm = 2.9;
        int    binning = 1;

        double computedScale() const {
            return focalLengthMm > 0.0
                ? 206.264806 * pixelSizeUm * binning / focalLengthMm : 0.0;
        }
        bool valid() const {
            return arcsecPerPixel > 0.0 && method != ScaleMethod::NotCalibrated;
        }
    };

    // -----------------------------------------------------------------------------
    //  Acquisition and centroiding
    // -----------------------------------------------------------------------------

    struct AcquisitionConfig {
        double detectThresholdSigma = 8.0;   // above background, for spot finding
        int    searchWindowPx = 48;    // tracking window once acquired
        double minSpotSeparationPx = 20.0;

        // Both spots are the same star, so their burst-mean fluxes should match to
        // within the wedge transmission. Single-frame ratios wander because
        // scintillation is only partly correlated between subapertures.
        double fluxRatioTolerance = 0.25;
        double expectedFluxRatio = 0.92;    // uncoated wedge, two Fresnel surfaces
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

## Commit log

2026-08-15 Added centroid processing and first cut at seeing monitor estimation.
2026-08-16 Added SVBony support. Updated centroid model to use interleaving. Added documentation of the synthetic camera stream's atmospheric model.
2026-08-16 Added Touptek support. Fun fact: The SVBony 715CC is actually a Touptek camera and won't show up under the SVBony SDK (Hence why Touptek is now implemented).
    [camera.h, toupcam_backend.cpp]
2026-08-17 Added DIMM mask STL for Orion ST80 and updated README re: mask STLs.
    [DIMM_MASK_80MMx53x25.4.stl]
2026-08-18 Added rolling time history for seeing and r0. Reworked the menu bars. Cleaned up some leftover LaTex problems in the README. Updated centroid detection to pick the best centroid pair and not refuse t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
    [config.h, main.cpp]
2026-08-18 Fixed my oopsie that broke build...
    Updated CMakeLists to [hopefully] build under the github Windows containers.
    [toupcam_backend.cpp]
2026-08-18 Workflow cleanup
    * Fixes to so the build works if alpaca is disabled.
    * Guard against copying DLLs under linux...
    [main.cpp]
2026-09-05 Yu coeffs (#3)
    * Added Yu/Sasiela coefficients. These are appropriate for all DIMM baseline configurations, but explicitly required if D/d < 2.
    * Corrected enums in config panel for K coefficients.
    * Fixed transverse hypergeometric series value, updated comments.
    [config.h]
